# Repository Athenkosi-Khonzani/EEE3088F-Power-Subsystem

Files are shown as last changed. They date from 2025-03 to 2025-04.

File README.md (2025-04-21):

# 🐭 Micro-Mouse Power Module  
### Power System for a Maze-Solving Robot

## 📌 Project Overview  
This project involves the design, development, and testing of a power module for a simplified micro-mouse robot. The micro-mouse is a small autonomous robot designed to navigate and solve a maze. While the processor, motherboard, and sensing modules are pre-designed, this project focuses exclusively on the power subsystem—an essential component responsible for delivering stable and reliable energy to all parts of the robot.

---

## ⚙️ Features  
- 🔋 **Battery Charging Circuitry** – Safely charges a lithium-ion battery using onboard circuitry (USB-C interface with USB hosting).  
- ⚡ **Power Distribution** – Provides regulated power to motors, sensors, processor, and other modules.  
- 🚗 **Motor Power Handling** – Supports high-current outputs required for driving motors.  
- 🧷 **Load Switches** – Supports additional switches to be used when required to drive high power loads.  
- 🔌 **USB-C Power Input** – Supports external USB-C charging and system powering.  
- 📉 **State-of-Charge (SOC) Monitoring** – Monitors battery voltage levels for feedback and safety. 

---

## 📦 What's Included  
- ✅ Circuit schematic (KiCad)  
- ✅ PCB layout  
- ✅ Bill of Materials (BOM)  
- ✅ Testing and validation documentation  
- ✅ I2C SOC readout
- ✅ SOC measurement logic

---

## ✅ Scope  
- Hardware design and testing of the power module  
- Battery management, charging, and safety  
- Power routing to all micro-mouse modules  
- ON/OFF logic and SOC measurement circuitry

---

## ❌ Not Included  
- Maze-solving algorithm and navigation logic  
- Mechanical assembly or robot chassis design  
- Sensor signal processing and interpretation  
- Processor firmware (Will be dealt with in design 2)

---

## 🛠️ Tools Used  
- 🖥️ KiCad
- 🔌 JLCPCB tools

## 👥 Contributors  
- **Athenkosi Khonzani [KHNATH002], Olwethu Khanzi [KHNOLW003]** – Power Module Design & Implementation  
- **Group 19**  

---

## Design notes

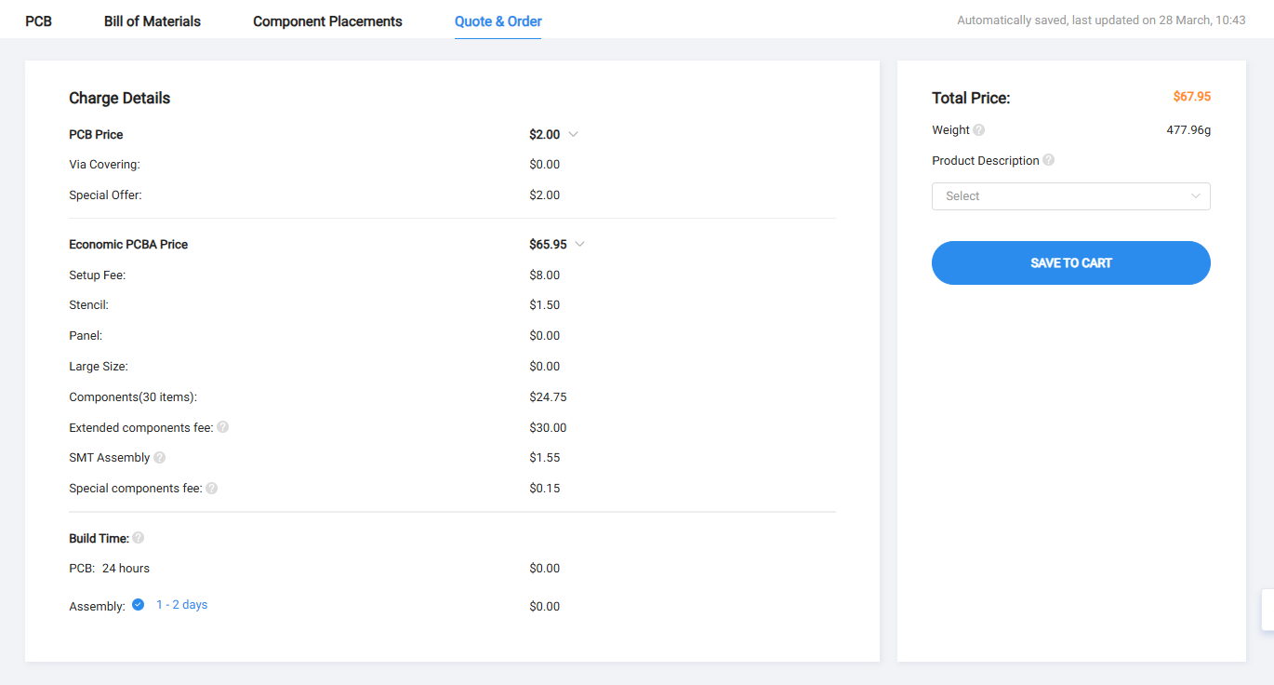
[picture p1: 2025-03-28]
EEE3088F-Power-Subsystem/Power_Module/jlcpcb/production_files/cart.png

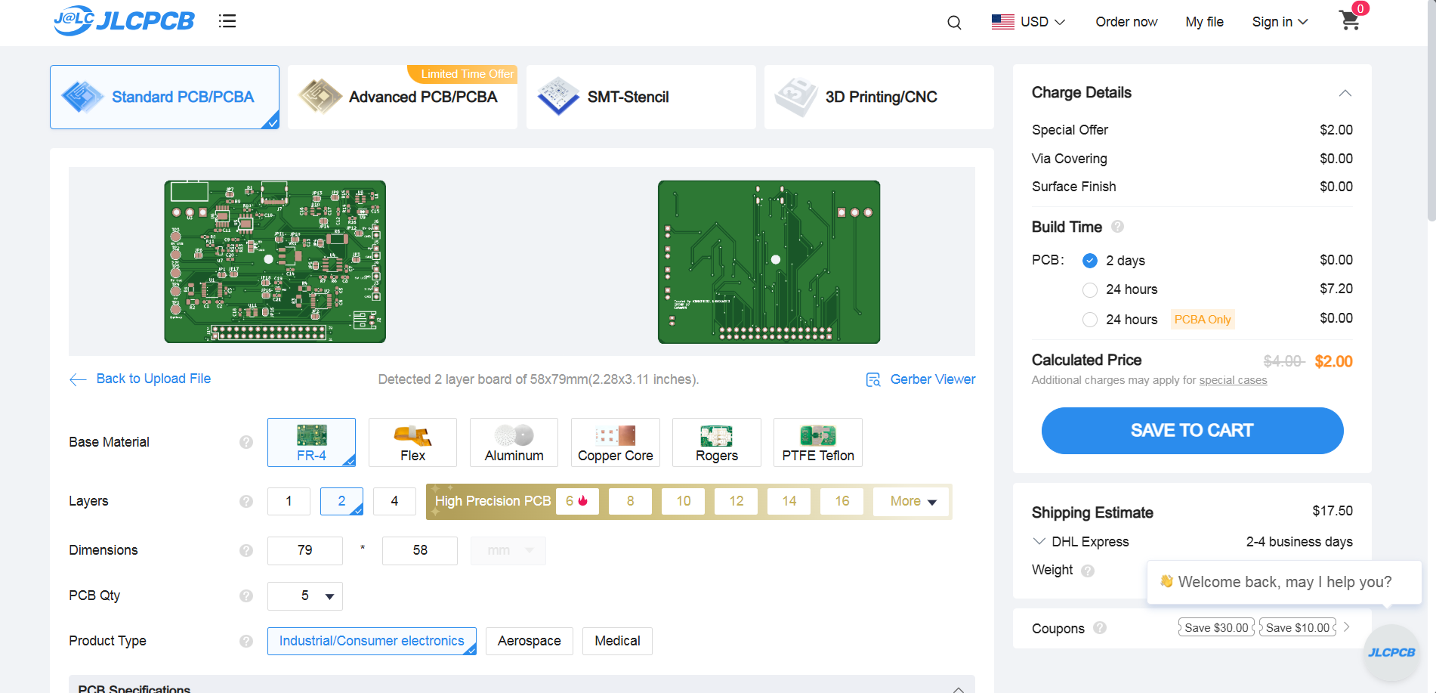
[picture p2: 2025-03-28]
EEE3088F-Power-Subsystem/Power_Module/jlcpcb/production_files/instant_quote.png

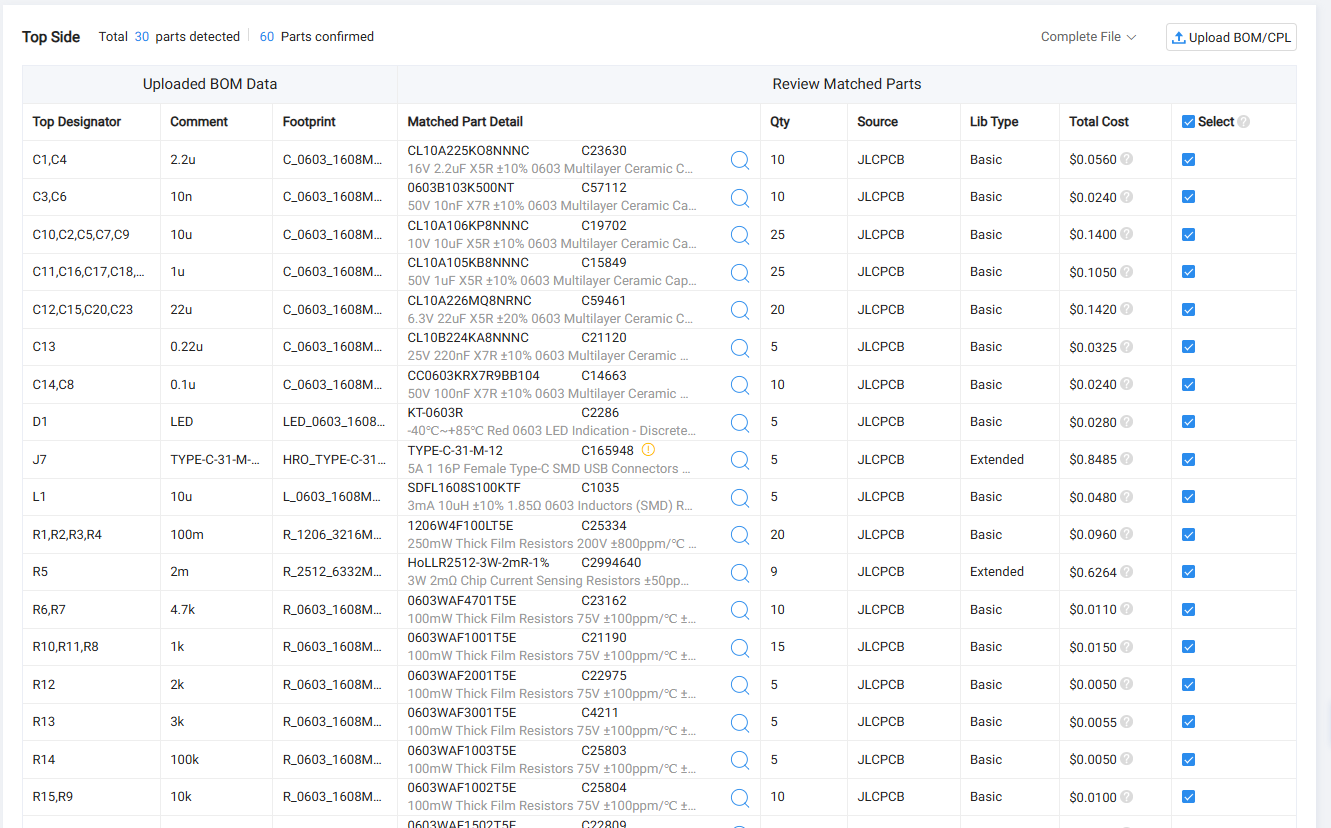
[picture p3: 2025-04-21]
EEE3088F-Power-Subsystem/Power_Module/New/EEE3088F_Project_JLCPCBBOM_KHNATH002_KHNOLW003.png

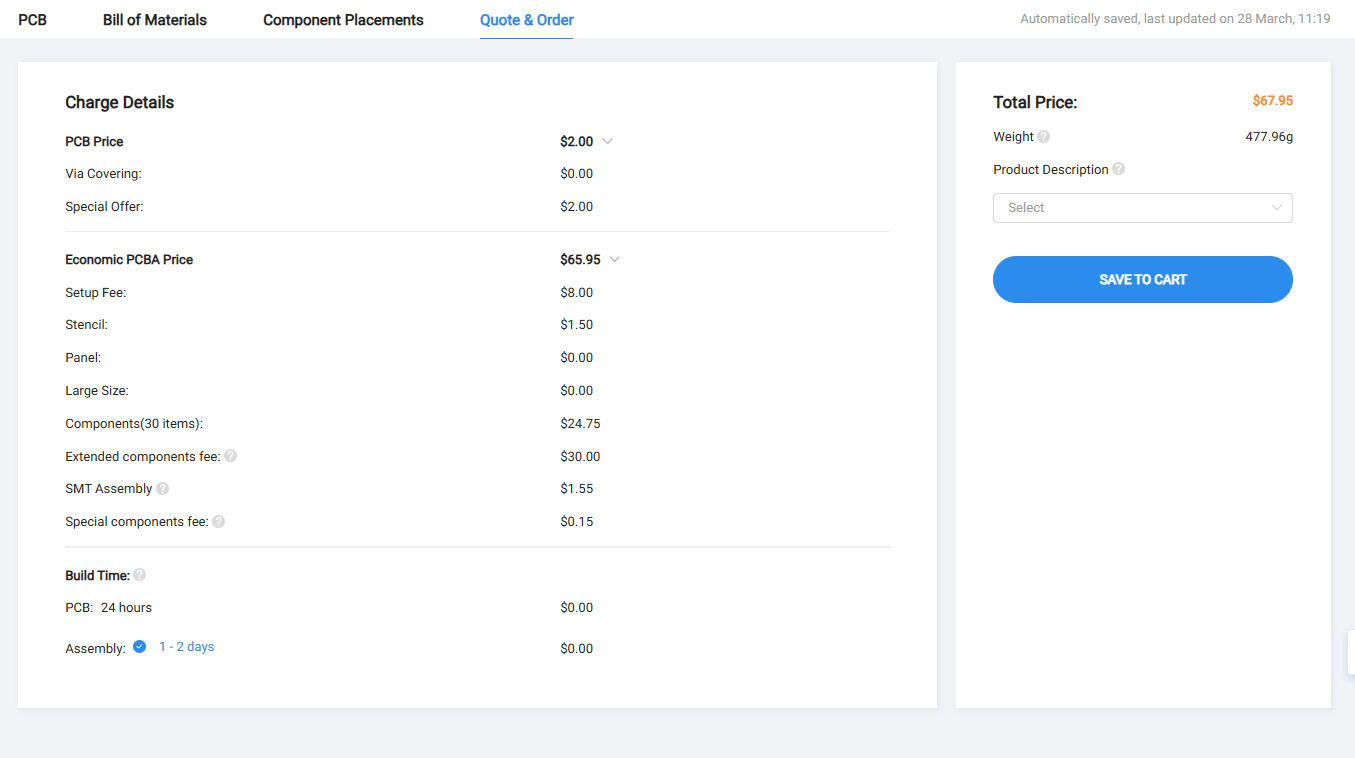
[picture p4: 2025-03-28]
EEE3088F-Power-Subsystem/Power_Module/jlcpcb/production_files/cart_page.png

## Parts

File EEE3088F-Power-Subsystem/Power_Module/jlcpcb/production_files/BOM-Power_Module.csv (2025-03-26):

Comment | Designator | Footprint | LCSC | Quantity
10u | L1 | L_0603_1608Metric_Pad1.05x0.95mm_HandSolder | C1035 | 1
INA219AxD | U2 | SOIC-8_3.9x4.9mm_P1.27mm | C138706 | 1
SiP32431DR3 | U7 | SOT-363_SC-70-6 | C141606 | 1
100n | C11,C13,C15,C21 | C_0603_1608Metric_Pad1.08x0.95mm_HandSolder | C14663 | 4
1u | C1,C10,C12,C18,C19 | C_0603_1608Metric_Pad1.08x0.95mm_HandSolder | C15849 | 5
TPB4056B2X-ES1R | U10 | ES1ESOP-8-F_TPK | C16581 | 1
TYPE-C-31-M-12 | J1 | HRO_TYPE-C-31-M-12 | C165948 | 1
MT3608 | U8 | SOT-23-6 | C19189893 | 1
10u | C20,C4,C6,C8,C9 | C_0603_1608Metric_Pad1.08x0.95mm_HandSolder | C19702 | 5
0.22u | C14 | C_0603_1608Metric_Pad1.08x0.95mm_HandSolder | C21120 | 1
1k | R2,R8 | R_0603_1608Metric_Pad0.98x0.95mm_HandSolder | C21190 | 2
NPN | Q1 | SOT-23 | C2145 | 1
15k | R10 | R_0603_1608Metric_Pad0.98x0.95mm_HandSolder | C22809 | 1
LED | D1 | LED_0603_1608Metric_Pad1.05x0.95mm_HandSolder | C2286 | 1
2k | R6 | R_0603_1608Metric_Pad0.98x0.95mm_HandSolder | C22975 | 1
4.7k | R4,R5 | R_0603_1608Metric_Pad0.98x0.95mm_HandSolder | C23162 | 2
AP2112K-3.3 | U9 | SOT-23-5 | C23380830 | 1
2.2u | C2,C5 | C_0603_1608Metric_Pad1.08x0.95mm_HandSolder | C23630 | 2
100m | R13,R15,R16,R17 | R_1206_3216Metric_Pad1.30x1.75mm_HandSolder | C25334 | 4
100k | R9 | R_0603_1608Metric_Pad0.98x0.95mm_HandSolder | C25803 | 1
10k | R1,R11 | R_0603_1608Metric_Pad0.98x0.95mm_HandSolder | C25804 | 2
LM7805MPX_NOPB | VR1 | VREG_LM7805MPX_NOPB | C2848241 | 1
2m | R3 | R_2512_6332Metric_Pad1.40x3.35mm_HandSolder | C2994640 | 1
3k | R7 | R_0603_1608Metric_Pad0.98x0.95mm_HandSolder | C4211 | 1
DRV8833PW | U3,U4 | TSSOP-16_4.4x5mm_P0.65mm | C50506 | 2
10n | C3,C7 | C_0603_1608Metric_Pad1.08x0.95mm_HandSolder | C57112 | 2
22u | C16,C17 | C_0603_1608Metric_Pad1.08x0.95mm_HandSolder | C59461 | 2
SM4007PL | D3 | SOD-123FL | C64898 | 1
CH224K | U1 | SSOP-10-1EP_3.9x4.9mm_P1mm_EP2.1x3.3mm | C970725 | 1
SiP32431DR3 | U6 | SOT-363_SC-70-6 |  | 1
SW_Wuerth_450301014042 | SW1 | SW_Slide-03_Wuerth-WS-SLTV_10x2.5x6.4_P2.54mm |  | 1
1k | R12 | R_0603_1608Metric_Pad0.98x0.95mm_HandSolder |  | 1

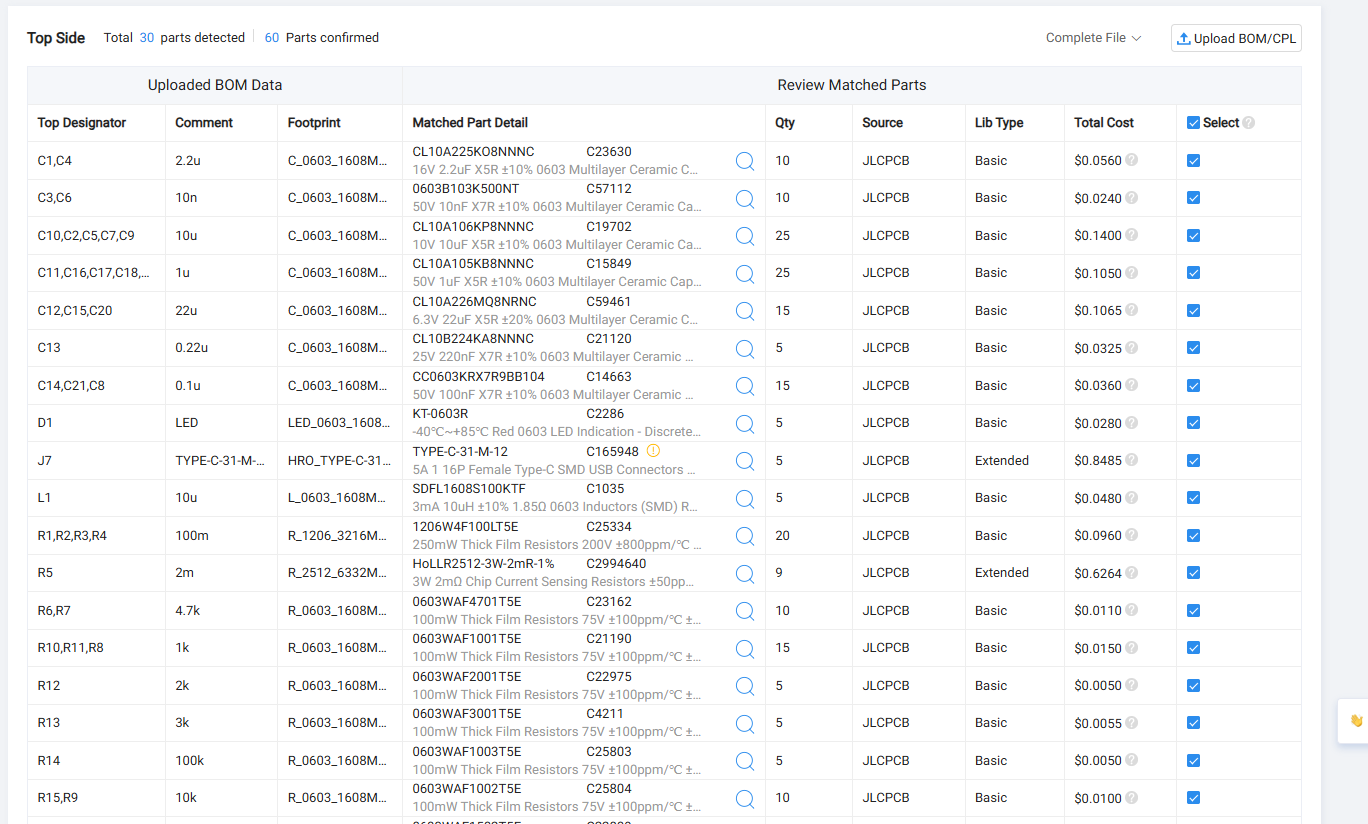
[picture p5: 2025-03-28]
EEE3088F-Power-Subsystem/Power_Module/jlcpcb/production_files/bom_page.png

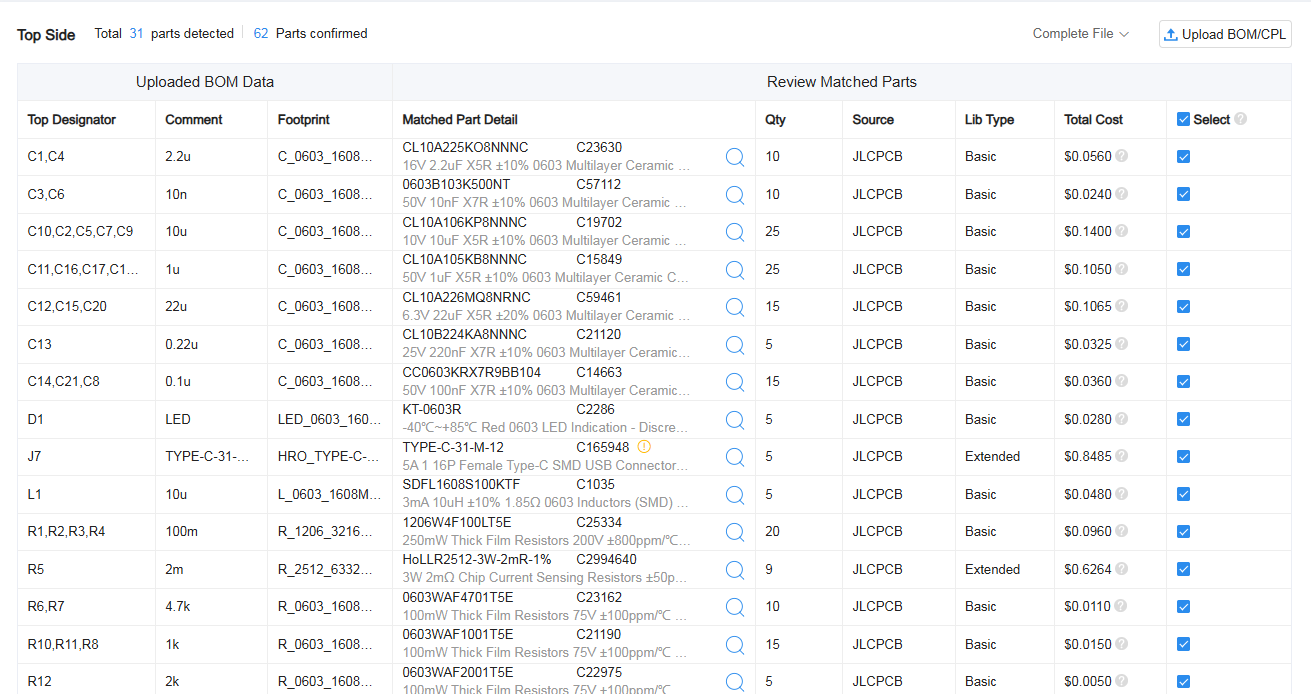
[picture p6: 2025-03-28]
EEE3088F-Power-Subsystem/Power_Module/jlcpcb/production_files/bom.png

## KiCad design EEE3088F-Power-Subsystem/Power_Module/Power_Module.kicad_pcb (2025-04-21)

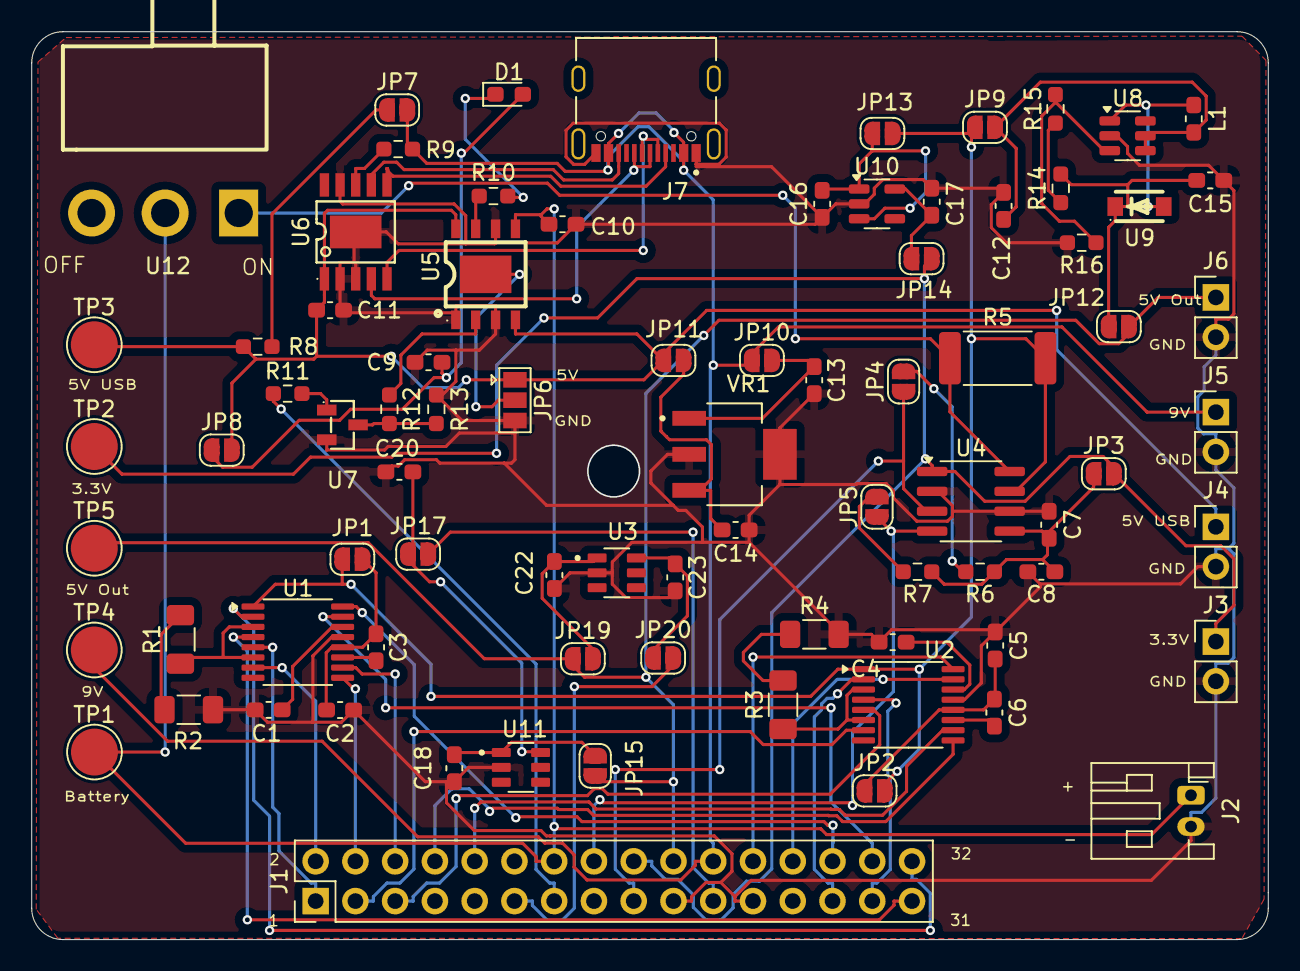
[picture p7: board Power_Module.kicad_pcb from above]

Board: 2 copper layers, 79.0 x 58.0 mm, 82 parts (0 on the bottom side), 68 nets.

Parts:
C1, C4: 2.2u; C_0603_1608Metric_Pad1.08x0.95mm_HandSolder
C2, C5, C7, C9, C10: 10u; C_0603_1608Metric_Pad1.08x0.95mm_HandSolder
C3, C6: 10n; C_0603_1608Metric_Pad1.08x0.95mm_HandSolder
C8, C14: 0.1u; C_0603_1608Metric_Pad1.08x0.95mm_HandSolder
C11, C16, C17, C18, C22: 1u; C_0603_1608Metric_Pad1.08x0.95mm_HandSolder
C12, C15, C20, C23: 22u; C_0603_1608Metric_Pad1.08x0.95mm_HandSolder
C13: 0.22u; C_0603_1608Metric_Pad1.08x0.95mm_HandSolder
D1: LED; LED_0603_1608Metric_Pad1.05x0.95mm_HandSolder
J1: Conn_02x16_Odd_Even; PinHeader_2x16_P2.54mm_Vertical
J2: Conn_01x02_Pin; JST_PH_S2B-PH-K_1x02_P2.00mm_Horizontal
J3, J4, J5, J6: Conn_01x02_Pin; PinHeader_1x02_P2.54mm_Vertical
J7: TYPE-C-31-M-12; HRO_TYPE-C-31-M-12
JP1: +M1_in; SolderJumper-2_P1.3mm_Open_RoundedPad1.0x1.5mm
JP2: +M2_in; SolderJumper-2_P1.3mm_Open_RoundedPad1.0x1.5mm
JP3: +3.3v_in; SolderJumper-2_P1.3mm_Open_RoundedPad1.0x1.5mm
JP4: pp_1; SolderJumper-2_P1.3mm_Open_RoundedPad1.0x1.5mm
JP5: pp_2; SolderJumper-2_P1.3mm_Open_RoundedPad1.0x1.5mm
JP6: EP; SolderJumper-3_P1.3mm_Open_Pad1.0x1.5mm
JP7: +9_main; SolderJumper-2_P1.3mm_Open_RoundedPad1.0x1.5mm
JP8: +5_ch; SolderJumper-2_P1.3mm_Open_RoundedPad1.0x1.5mm
JP9: +3.7_b; SolderJumper-2_P1.3mm_Open_RoundedPad1.0x1.5mm
JP10: +9V_in; SolderJumper-2_P1.3mm_Open_RoundedPad1.0x1.5mm
JP11: +5v_l; SolderJumper-2_P1.3mm_Open_RoundedPad1.0x1.5mm
JP12: +5_out; SolderJumper-2_P1.3mm_Open_RoundedPad1.0x1.5mm
JP13: +3.7_l; SolderJumper-2_P1.3mm_Open_RoundedPad1.0x1.5mm
JP14: +3.3_l2; SolderJumper-2_P1.3mm_Open_RoundedPad1.0x1.5mm
JP15: sip_in_1; SolderJumper-2_P1.3mm_Open_RoundedPad1.0x1.5mm
JP17: sip_out_1; SolderJumper-2_P1.3mm_Open_RoundedPad1.0x1.5mm
JP19: sip_in_2; SolderJumper-2_P1.3mm_Open_RoundedPad1.0x1.5mm
JP20: sip_out_2; SolderJumper-2_P1.3mm_Open_RoundedPad1.0x1.5mm
L1: 10u; L_0603_1608Metric_Pad1.05x0.95mm_HandSolder
R1, R2, R3, R4: 100m; R_1206_3216Metric_Pad1.30x1.75mm_HandSolder
R5: 2m; R_2512_6332Metric_Pad1.40x3.35mm_HandSolder
R6, R7: 4.7k; R_0603_1608Metric_Pad0.98x0.95mm_HandSolder
R8, R10, R11: 1k; R_0603_1608Metric_Pad0.98x0.95mm_HandSolder
R9, R15: 10k; R_0603_1608Metric_Pad0.98x0.95mm_HandSolder
R12: 2k; R_0603_1608Metric_Pad0.98x0.95mm_HandSolder
R13: 3k; R_0603_1608Metric_Pad0.98x0.95mm_HandSolder
R14: 100k; R_0603_1608Metric_Pad0.98x0.95mm_HandSolder
R16: 15k; R_0603_1608Metric_Pad0.98x0.95mm_HandSolder
TP1: +Batt; TestPoint_Pad_D3.0mm
TP2: +3.3V; TestPoint_Pad_D3.0mm
TP3: +5V; TestPoint_Pad_D3.0mm
TP4: +9V_usb; TestPoint_Pad_D3.0mm
TP5: 5V_out; TestPoint_Pad_D3.0mm
U1, U2: DRV8833PW; TSSOP-16_4.4x5mm_P0.65mm
U3, U11: TPS22810DBVR; SOT95P280X145-6N
U4: INA219AxD; SOIC-8_3.9x4.9mm_P1.27mm
U5: TP4056; ESOP-8_L4.9-W3.9-P1.27-LS6.0-BL-EP
U6: CH224K; ESSOP-10_L4.9-W3.9-P1.0-LS6.0-TL-EP
U7: MMBT5551_C2145; SOT-23-3_L2.9-W1.3-P1.90-LS2.4-BR
U8: MT3608; SOT-23-6
U9: SM4007PL; SOD-123F_L2.8-W1.8-LS3.7-RD
U10: AP2112K-3.3; SOT-23-5
U12: SS-12D06L5; SW-TH_3P-P4.70_L11.1-W12.7
VR1: LM7805MPX_NOPB; VREG_LM7805MPX_NOPB

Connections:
5V_out: J1.20, J6.1, JP12.2 (B), JP15.1 (A), JP19.1 (A), TP5.1
+3.3V: J1.18, J3.1, JP3.2 (B), JP14.2 (B), TP2.1, U4.1 (A1)
+5V: C11.1, J4.1, JP6.1 (A), JP8.2 (B), JP11.2 (B), R8.2, TP3.1, U5.4 (VCC), U5.8 (CE), U6.1 (VDD)
+9V: J1.22, J5.1, J7.A4_B9 (VBUS), J7.B4_A9 (VBUS), JP7.2 (B), JP10.1 (A), R9.1, TP4.1
+BATT: C10.1, J1.14, J2.1, TP1.1, U5.5 (BAT), U12.2
/Motor_Drivers/VCP1: C3.2, U1.11 (VCP)
/Motor_Drivers/VCP2: C6.2, U2.11 (VCP)
/Usb_Charging/CHRG: R10.2, U5.7 (CHRG#)
/Usb_Charging/DM: J7.A7 (DN1), J7.B7 (DN2), U6.5 (DM)
/Usb_Charging/DP: J7.A6 (DP1), J7.B6 (DP2), U6.4 (DP)
/Usb_Charging/RPROG: R12.1, U5.2 (PROG)
FAST_CHRG_CTRL: J1.13, R11.1
GND: C1.1, C2.2, C4.1, C5.2, C7.2, C8.2, C9.2, C10.2, C11.2, C12.2, C13.2, C14.2, C15.2, C16.2, C17.2, C18.2, C20.2, C22.2, C23.2, J1.19, J1.23, J2.2, J3.2, J4.2, J5.2, J6.2, J7.A1_B12 (GND), J7.B1_A12 (GND), JP6.3 (B), R2.2, R4.2, R13.2, R16.2, U1.13 (GND), U2.13 (GND), U3.2 (GND), U4.2 (A0), U4.6 (GND), U5.1 (TEMP), U5.3 (GND), U5.6 (STDBY#), U6.2 (CFG2), U6.3 (CFG3), U6.9 (CFG1), U6.11 (GND), U7.2 (E), U8.2 (GND), U10.2 (GND), U11.2 (GND), VR1.2 (GND_2), VR1.4 (GND_4)
LOAD: JP1.2 (B), JP2.2 (B), JP9.1 (A), JP13.1 (A), R5.2, U1.1 (~SLEEP), U2.1 (~SLEEP), U4.7 (IN-)
LOUT1: J1.21, JP17.2 (B)
LOUT2: J1.11, JP20.2 (B)
M1_A_IN: J1.28, U1.16 (AIN1)
M1_A_OUT: J1.32, U1.2 (AOUT1)
M1_B_IN: J1.30, U1.15 (AIN2)
M1_B_OUT: J1.31, U1.4 (AOUT2)
M2_A_IN: J1.4, U1.9 (BIN1)
M2_A_OUT: J1.2, U1.7 (BOUT1)
M2_B_IN: J1.6, U1.10 (BIN2)
M2_B_OUT: J1.1, U1.5 (BOUT2)
M3_A_IN: J1.24, U2.16 (AIN1)
M3_A_OUT: J1.27, U2.2 (AOUT1)
M3_B_IN: J1.26, U2.15 (AIN2)
M3_B_OUT: J1.29, U2.4 (AOUT2)
M4_A_IN: J1.8, U2.9 (BIN1)
M4_A_OUT: J1.3, U2.7 (BOUT1)
M4_B_IN: J1.10, U2.10 (BIN2)
M4_B_OUT: J1.5, U2.5 (BOUT2)
unnamed: C9.1, D1.2 (A), JP8.1 (A)
unnamed: D1.1 (K), R10.1
unnamed: J7.A5 (CC1), U6.6 (CC2)
unnamed: J7.B5 (CC2), U6.7 (CC1)
unnamed: C2.1, C3.1, JP1.1 (A), U1.12 (VM)
unnamed: C5.1, C6.1, JP2.1 (A), U2.12 (VM)
unnamed: C7.1, C8.1, JP3.1 (A), R6.1, R7.1, U4.5 (VS)
unnamed: JP4.2 (B), R6.2
unnamed: JP5.2 (B), R7.2
unnamed: JP6.2 (C), U5.9 (EP)
unnamed: JP7.1 (A), R8.1
unnamed: C12.1, JP9.2 (B), L1.1, U8.4 (EN), U8.5 (IN)
unnamed: C13.1, JP10.2 (B), VR1.1 (INPUT)
unnamed: C14.1, JP11.1 (A), VR1.3 (OUTPUT)
unnamed: C15.1, JP12.1 (A), R14.1, U9.1 (C)
unnamed: C16.1, JP13.2 (B), U10.1 (VIN), U10.3 (EN)
unnamed: C17.1, JP14.1 (A), U10.5 (VOUT)
unnamed: C18.1, JP15.2 (B), U11.1 (VIN)
unnamed: C20.1, JP17.1 (A), U11.6 (VOUT)
unnamed: C22.1, JP19.2 (B), U3.1 (VIN)
unnamed: C23.1, JP20.1 (A), U3.6 (VOUT)
unnamed: R1.2, R2.1
unnamed: R3.2, R4.1
unnamed: R14.2, R15.1
unnamed: R1.1, U1.3 (AISEN), U1.6 (BISEN)
unnamed: C1.2, U1.14 (VINT)
unnamed: R3.1, U2.3 (AISEN), U2.6 (BISEN)
unnamed: C4.2, U2.14 (VINT)
unnamed: R5.1, U4.8 (IN+), U12.1
unnamed: R9.2, U6.8 (VBUS)
unnamed: R11.2, U7.1 (B)
unnamed: R12.2, R13.1, U7.3 (C)
unnamed: R15.2, R16.1, U8.3 (FB)
unnamed: L1.2, U8.1 (SW), U9.2 (A)
SCL: J1.16, JP5.1 (A), U4.4 (SCL)
SDA: J1.17, JP4.1 (A), U4.3 (SDA)

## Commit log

2025-03-23 First commit empty
    [Power_Module.kicad_pcb, Power_Module.kicad_sch]
2025-03-23 Basic structure in place; Need to put regulators
    [monitoring.kicad_sch, motor_drivers.kicad_sch, usb_charging.kicad_sch]
2025-03-23 Regulators in place - Protection circuitry neeeded
2025-03-23 Add main switch - still need to put in the right place
2025-03-23 All changes saved
    [Power_Module.kicad_sch, load_switches.kicad_sch, monitoring.kicad_sch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]
2025-03-25 Added the main connector; fixed the labels; We need a switch
    [Power_Module.kicad_sch, load_switches.kicad_sch, monitoring.kicad_sch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]
2025-03-25 Fixed minor but fundamental error
    [Power_Module.kicad_sch, motor_drivers.kicad_sch]
2025-03-25 Footprints added for all equipment; we still need to add protection circuitry
    [Power_Module.kicad_sch, load_switches.kicad_sch, monitoring.kicad_sch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]
2025-03-25 fixed diode error
    [regulators.kicad_sch]
2025-03-26 Connectors and jumpers added. But there's still errors for some reason
    [Power_Module.kicad_sch, load_switches.kicad_sch, monitoring.kicad_sch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]
2025-03-26 INA219 improved
    [monitoring.kicad_sch]
2025-03-26 jlcpcb tools installed
    [BOM-Power_Module.csv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]
2025-03-27 BASIC LAYOUT PUT: BAZIC LAYOUT PUT
    [Power_Module.kicad_pcb]
2025-03-27 Alot has happened honestly
    [load_switches.kicad_sch, monitoring.kicad_sch, motor_drivers.kicad_sch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]
2025-03-28 Started pcb layout, still looking good
    [Power_Module.kicad_pcb]
2025-03-28 Last commit, messy though
    [BOM-Power_Module.csv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]
2025-04-21 Last commit
    [BOM-Power_Module.csv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]
